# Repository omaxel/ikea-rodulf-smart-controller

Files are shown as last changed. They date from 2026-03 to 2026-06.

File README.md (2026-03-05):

# IKEA RODULF Sit/Stand Desk - WiFi Automation
Turn your manual IKEA RODULF desk into a smart, WiFi-controlled desk using an ESP8266 (NodeMCU) and a 2-channel relay module. Control it from any browser on your local network.

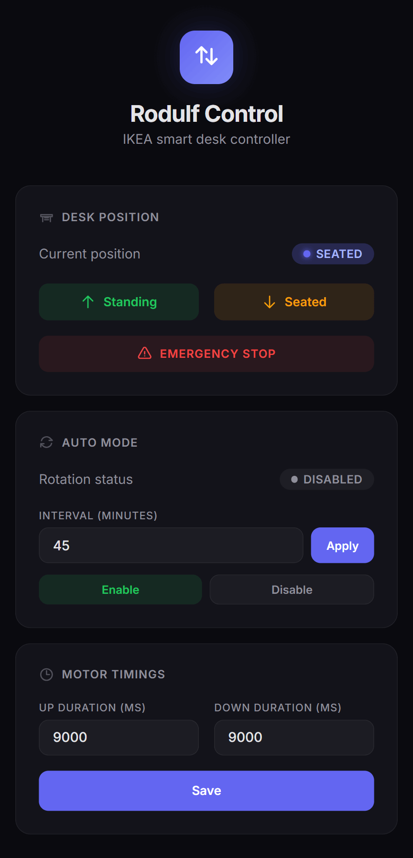
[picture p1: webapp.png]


## Table of Contents

- [Features](#features)
- [Hardware Requirements](#hardware-requirements)
- [Wiring & Connections](#wiring--connections)
- [Getting Started](#getting-started)
- [Repository Structure](#repository-structure)
- [Web Interface](#web-interface)
- [API Reference](#api-reference)
- [Limitations](#limitations)
- [Possible Improvements](#possible-improvements)

## Features

- **Remote control**: raise or lower the desk from any device on your WiFi network.
- **Original desk buttons still work**: relays are wired *in parallel* with the built-in buttons, so physical control is never disabled.
- **Auto-rotate mode**: automatically alternates between sitting and standing at a configurable interval (e.g. every 30 min).
- **Configurable motor timings**: set independent durations (ms) for up and down movements.
- **Persistent configuration**: all settings are saved to flash (LittleFS) and survive reboots.
- **Emergency stop**: instantly cuts power to both relays from the web UI.
- **Minimal footprint**: the entire UI is a single minified HTML page served from the ESP8266. No external server or cloud.

## Hardware Requirements

| Component | Qty | Notes |
|---|---|---|
| ESP8266 NodeMCU v1.0 (or compatible) | 1 | Wemos D1 Mini also works |
| 2-Channel 5 V Relay Module | 1 | Active-LOW, opto-isolated recommended |
| 5 V USB power supply | 1 | Powers the NodeMCU via micro-USB |
| IKEA RODULF sit/stand desk | 1 | Manual model with built-in up/down buttons |

## Wiring & Connections

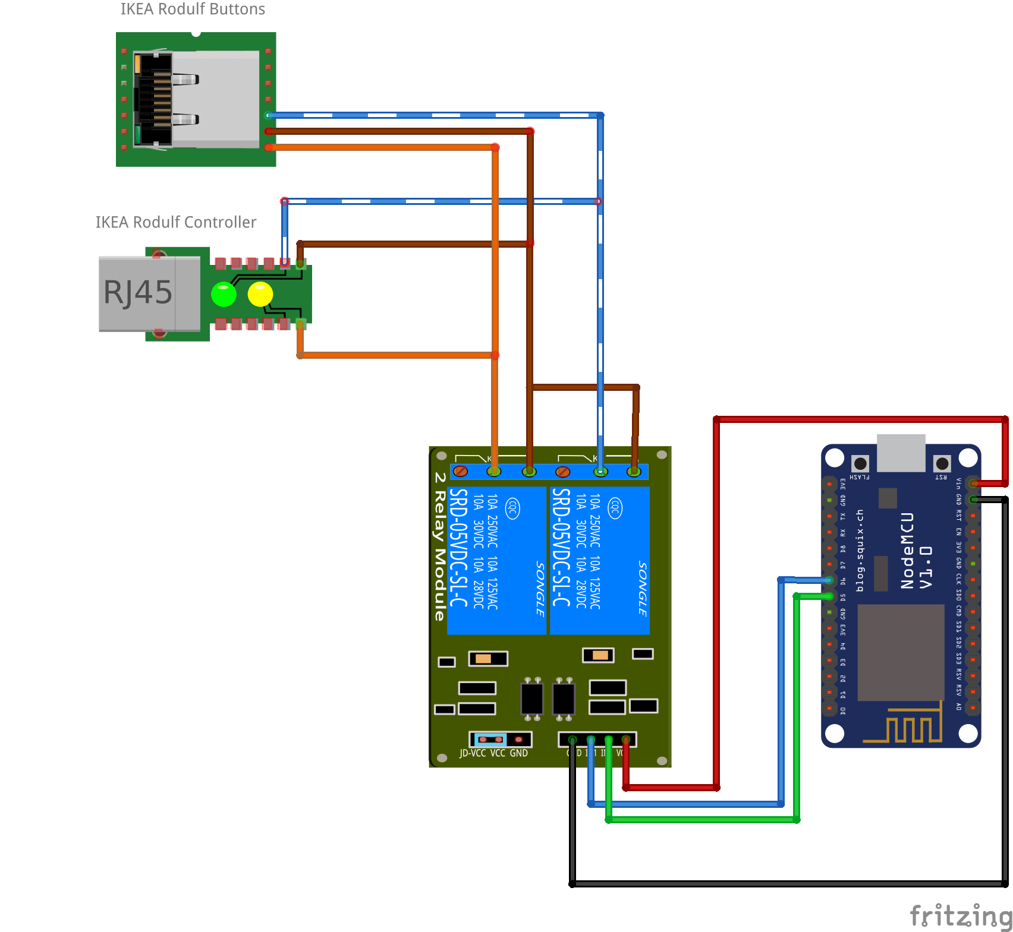
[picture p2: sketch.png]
Wiring diagram


### Relay Module to NodeMCU

| Relay Pin | NodeMCU Pin | Purpose |
|---|---|---|
| VCC | VIN (5 V) | Powers the relay coils |
| GND | GND | Common ground |
| IN1 | D5 | Relay 1 (UP) |
| IN2 | D6 | Relay 2 (DOWN) |

### Relay Module to Desk Buttons (RJ-45 Cable)

The RODULF desk buttons connect to an internal controller board via an **RJ-45 cable**. Only three of the eight wires are relevant:

| RJ-45 Wire Color | Function |
|---|---|
| **Orange** | DOWN signal |
| **Blue/white** | UP signal |
| **Brown** | Common (GND) |

The buttons work by shorting the signal wire to brown (GND). The relays are wired in parallel with these signals:

- **Relay 1 (UP)**: `COM` to brown wire, `NO` to blue/white wire.
- **Relay 2 (DOWN)**: `COM` to brown wire, `NO` to orange wire.

The RJ-45 output from the relay assembly must still be connected to the RODULF controller board so the desk receives the signals. Because the wiring is in parallel, the original physical buttons continue to work normally.

> **Important:** Use the `NO` (Normally Open) terminal on each relay, not `NC`. This keeps the motor off by default.

### Power

- NodeMCU is powered via micro-USB from a 5 V adapter.
- The relay module draws 5 V from the NodeMCU's VIN pin.
- The desk motor uses its own internal power supply; you are only switching button signals, not motor power.

## Getting Started

### 1. Install Arduino IDE & Board Support

1. Install the [Arduino IDE](https://www.arduino.cc/en/software) (v1.8+ or v2.x).
2. In **File > Preferences**, add this URL to **Additional Board Manager URLs**:
   ```
   http://arduino.esp8266.com/stable/package_esp8266com_index.json
   ```
3. In **Tools > Board > Board Manager**, search for `esp8266` and install the package.

### 2. Configure the Sketch

1. Open `ikea_rodulf_automation/ikea_rodulf_automation.ino`.
2. Set your WiFi credentials:
   ```cpp
   const char* ssid = "YourWiFiName";
   const char* password = "YourWiFiPassword";
   ```
3. (Optional) Adjust defaults:
   ```cpp
   // {timeUpMs, timeDownMs, isStanding, autoModeActive, autoIntervalMs}
   DeskConfig myConfig = {9000, 9000, false, false, 1800000};
   ```

### 3. Upload

1. Connect the NodeMCU via USB.
2. Select **Board:** `NodeMCU 1.0 (ESP-12E Module)` and the correct **Port**.
3. Set **Flash Size** to a partition with LittleFS (e.g. `4MB (FS:2MB OTA:~1019KB)`).
4. Click **Upload**.

### 4. Find the IP Address

Open **Serial Monitor** at 115200 baud after upload, or check your router's DHCP client list.

### 5. Open the Control Panel

Navigate to `http://<ESP_IP>/` from any browser on the same network.

### 6. (Optional) Developing the Frontend

```bash
cd frontend
npm install
npm run build     # produces index.min.html
```

Copy the minified output into the `handleRoot()` raw string in the `.ino` file.

## Repository Structure

```
├── README.md
├── sketch.png                         # Wiring diagram image
├── sketch.fzz                         # Fritzing source (editable)
├── fritzing_parts/                    # Custom Fritzing components
│   ├── 2-Channel 5v Relay Shield-fixed.fzpz
│   └── NodeMCUV1.0.fzpz
├── ikea_rodulf_automation/
│   └── ikea_rodulf_automation.ino     # Arduino sketch (ESP8266)
└── frontend/
    ├── index.html                     # Readable web UI source
    ├── index.min.html                 # Minified build (embedded in .ino)
    ├── package.json                   # npm build script
    └── package-lock.json
```

## Web Interface

Single HTML page with embedded CSS/JS. No frameworks or external dependencies at runtime.

- **Desk Position**: current state badge (Standing/Seated/Offline), buttons for up, down, and emergency stop.
- **Auto Mode**: enable/disable toggle and interval setting (minutes).
- **Motor Timings**: configure up/down relay duration (ms) and save to flash.
- **Auto-refresh**: polls `/status` every 3 seconds.

## API Reference

All endpoints use `GET` for simplicity.

| Endpoint | Parameters | Description |
|---|---|---|
| `/` | | Control panel (HTML) |
| `/status` | | JSON with current state |
| `/standing` | | Move desk up |
| `/seated` | | Move desk down |
| `/stop` | | Emergency stop |
| `/auto` | `enable=1\|0`, `interval=<min>` | Configure auto-rotate |
| `/config/set` | `up=<ms>`, `down=<ms>` | Set motor durations |

**Example `/status` response:**

```json
{
  "heightState": "standing",
  "autoMode": true,
  "intervalMinutes": 30,
  "timeUpMs": 9000,
  "timeDownMs": 9000,
  "isMoving": false
}
```

## Limitations

- **No position sensor**: the system tracks direction only, not actual height. Using the physical buttons will desync the reported state.
- **Timing calibration required**: you must measure your desk's actual travel time and enter it manually.
- **DHCP only**: the IP may change if your router reassigns it.
- **No authentication or HTTPS**: anyone on the same network can control the desk.

## Possible Improvements

- **mDNS**: reach the desk at `http://rodulf.local/` via `ESP8266mDNS`.
- **OTA updates**: flash new firmware over WiFi with `ArduinoOTA`.
- **Height sensor**: add HC-SR04 or VL53L0X for real position feedback.
- **Authentication**: basic HTTP auth or API key.
- **MQTT / Home Assistant**: publish state and accept commands over MQTT.
- **Button state detection**: read physical button signals on ESP8266 inputs to keep state in sync.
- **WebSocket updates**: replace polling with push for instant UI refresh.

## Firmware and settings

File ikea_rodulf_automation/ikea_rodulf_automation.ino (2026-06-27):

#include <ESP8266WiFi.h>
#include <ESP8266WebServer.h>
#include <LittleFS.h>

const char* ssid = "<SSID_HERE>";
const char* password = "<PASSWORD_HERE>";

const int relayUp = D5;    
const int relayDown = D6;

struct DeskConfig {
  unsigned long timeUpMs;      
  unsigned long timeDownMs;    
  bool isStanding;             
  bool autoModeActive;         
  unsigned long autoIntervalMs; 
};

DeskConfig myConfig = {9000, 9000, false, false, 1800000}; 
const char* CONFIG_PATH = "/desk_config.bin";

ESP8266WebServer server(80);
unsigned long movementStartTime = 0;   
unsigned long currentTargetDuration = 0; 
unsigned long lastAutoToggleTime = 0;   
bool isMoving = false;                 

// --- Persistence ---
void saveConfig() {
  File file = LittleFS.open(CONFIG_PATH, "w");
  if (file) {
    file.write((uint8_t*)&myConfig, sizeof(DeskConfig));
    file.close();
  }
}

void loadConfig() {
  if (LittleFS.exists(CONFIG_PATH)) {
    File file = LittleFS.open(CONFIG_PATH, "r");
    if (file) {
      file.read((uint8_t*)&myConfig, sizeof(DeskConfig));
      file.close();
    }
  }
}

// --- Motors ---
void stopMotors() {
  digitalWrite(relayUp, HIGH);
  digitalWrite(relayDown, HIGH);
  isMoving = false;
  movementStartTime = 0;
}

void startMovement(int pin, unsigned long duration, bool toStanding) {
  if (isMoving) return; 
  currentTargetDuration = duration;
  movementStartTime = millis();
  isMoving = true;
  myConfig.isStanding = toStanding;
  saveConfig(); 
  digitalWrite(pin, LOW); 
}

// --- Web Page HTML ---
void handleRoot() {
  String html = F(R"=====(
<!doctype html><html lang=en><meta charset=UTF-8><meta name=viewport content="width=device-width,initial-scale=1,viewport-fit=cover"><title>IKEA Rodulf Control Panel</title><link rel=preconnect href=https://fonts.googleapis.com><link href="https://fonts.googleapis.com/css2?family=Inter:wght@300;400;500;600;700&display=swap" rel=stylesheet><style>*,:before,:after{box-sizing:border-box;margin:0;padding:0}:root{--bg:#0a0a0f;--surface:#13131a;--surface-hover:#1a1a24;--border:#ffffff0f;--border-hover:#ffffff1f;--text:#e4e4e7;--text-dim:#8f8f9b;--accent:#6366f1;--accent-glow:#6366f140;--green:#22c55e;--green-dim:#22c55e1f;--amber:#f59e0b;--amber-dim:#f59e0b1f;--red:#ef4444;--red-dim:#ef44441a;--radius:16px;--radius-sm:10px}body{background:var(--bg);color:var(--text);min-height:-webkit-fill-available;padding:2rem 1rem;padding-top:max(2rem, env(safe-area-inset-top,0px));padding-bottom:max(2rem, env(safe-area-inset-bottom,0px));padding-left:max(1rem, env(safe-area-inset-left,0px));padding-right:max(1rem, env(safe-area-inset-right,0px));-webkit-font-smoothing:antialiased;font-family:Inter,-apple-system,BlinkMacSystemFont,sans-serif}.wrapper{max-width:720px;margin:0 auto}header{text-align:center;margin-bottom:2.5rem}header .logo{background:linear-gradient(135deg, var(--accent), #818cf8);width:56px;height:56px;box-shadow:0 0 32px var(--accent-glow);border-radius:16px;justify-content:center;align-items:center;margin-bottom:1rem;display:inline-flex}header .logo svg{color:#fff;width:28px;height:28px}header h1{letter-spacing:-.025em;margin-bottom:.25rem;font-size:1.5rem;font-weight:700}header p{color:var(--text-dim);font-size:.875rem;font-weight:400}.card{background:var(--surface);border:1px solid var(--border);border-radius:var(--radius);padding:1.5rem;transition:border-color .2s}.card:hover{border-color:var(--border-hover)}.card+.card{margin-top:1rem}.card-title{text-transform:uppercase;letter-spacing:.06em;color:var(--text-dim);align-items:center;gap:.5rem;margin-bottom:1.25rem;font-size:.75rem;font-weight:600;display:flex}.card-title svg{opacity:.5;width:16px;height:16px}.grid-2{grid-template-columns:1fr 1fr;gap:1rem;display:grid}.badge{letter-spacing:.03em;border-radius:999px;align-items:center;gap:6px;padding:4px 12px;font-size:.75rem;font-weight:600;display:inline-flex}.badge .dot{border-radius:50%;width:7px;height:7px;display:inline-block}.badge--active{background:var(--green-dim);color:var(--green)}.badge--active .dot{background:var(--green);box-shadow:0 0 6px var(--green)}.badge--inactive{color:var(--text-dim);background:#71717a1f}.badge--inactive .dot{background:var(--text-dim)}.badge--accent{background:var(--accent-glow);color:#a5b4fc}.badge--accent .dot{background:var(--accent);box-shadow:0 0 6px var(--accent)}.status-row{justify-content:space-between;align-items:center;margin-bottom:1.25rem;display:flex}.status-row span:first-child{color:var(--text-dim);font-size:.875rem}.btn{border-radius:var(--radius-sm);cursor:pointer;border:none;outline:none;justify-content:center;align-items:center;gap:8px;width:100%;padding:.7rem 1.25rem;font-family:inherit;font-size:.8125rem;font-weight:600;transition:all .15s;display:inline-flex}.btn svg{flex-shrink:0;width:16px;height:16px}.btn--stand{background:var(--green-dim);color:var(--green)}.btn--stand:hover{background:#22c55e38}.btn--sit{background:var(--amber-dim);color:var(--amber)}.btn--sit:hover{background:#f59e0b38}.btn--stop{background:var(--red-dim);color:var(--red);text-transform:uppercase;letter-spacing:.06em;grid-column:1/-1;font-size:.75rem}.btn--stop:hover{background:#ef444433}.btn--accent{background:var(--accent);color:#fff}.btn--accent:hover{box-shadow:0 0 20px var(--accent-glow);background:#4f46e5}.btn--ghost{color:var(--text-dim);border:1px solid var(--border);background:#ffffff0a}.btn--ghost:hover{color:var(--text);border-color:var(--border-hover);background:#ffffff14}.btn--sm{padding:.5rem 1rem;font-size:.75rem}.btn-group{gap:.5rem;display:flex}.field{flex-direction:column;gap:.375rem;display:flex}.field label{text-transform:uppercase;letter-spacing:.05em;color:var(--text-dim);font-size:.6875rem;font-weight:500}.input{color:var(--text);border:1px solid var(--border);border-radius:var(--radius-sm);background:#ffffff0a;outline:none;width:100%;padding:.6rem .875rem;font-family:inherit;font-size:.875rem;font-weight:500;transition:border-color .2s,box-shadow .2s}.input:focus{border-color:var(--accent);box-shadow:0 0 0 3px var(--accent-glow)}.input::placeholder{color:var(--text-dim)}.input::-webkit-inner-spin-button,.input::-webkit-outer-spin-button{-webkit-appearance:none;margin:0}.input[type=number]{-moz-appearance:textfield}.inline-field{gap:.5rem;display:flex}.inline-field .input{flex:1}.inline-field .btn{white-space:nowrap;width:auto}.timing-grid{grid-template-columns:1fr 1fr auto;align-items:end;gap:1rem;display:grid}.toast{background:var(--surface);border:1px solid var(--border-hover);border-radius:var(--radius-sm);color:var(--text);opacity:0;pointer-events:none;z-index:100;padding:.6rem 1.25rem;font-size:.8125rem;font-weight:500;transition:all .3s cubic-bezier(.16,1,.3,1);position:fixed;bottom:1.5rem;left:50%;transform:translate(-50%)translateY(100%);box-shadow:0 8px 32px #0006}.toast.show{opacity:1;transform:translate(-50%)translateY(0)}.toast{bottom:max(1.5rem, env(safe-area-inset-bottom,0px))}@media (width<=600px){.timing-grid{grid-template-columns:1fr 1fr}.timing-grid .btn{grid-column:1/-1}}@keyframes pulse{0%,to{opacity:1}50%{opacity:.4}}.pulse{animation:1.5s ease-in-out infinite pulse}@supports not (min-height:100dvh){body{min-height:calc(var(--vh,1vh) * 100)}}</style><div class=wrapper><header><div class=logo><svg xmlns="http://www.w3.org/2000/svg" fill="none" viewBox="0 0 24 24" stroke-width="2" stroke="currentColor"><path stroke-linecap="round" stroke-linejoin="round" d="M3 7.5 7.5 3m0 0L12 7.5M7.5 3v13.5m13.5-3L16.5 18m0 0L12 13.5m4.5 4.5V4.5"/></svg></div><h1>Rodulf Control</h1><p>IKEA smart desk controller</header><div class=card><div class=card-title><svg xmlns="http://www.w3.org/2000/svg" fill="none" viewBox="0 0 24 24" stroke-width="2" stroke="currentColor" aria-hidden="true"><path stroke-linecap="round" stroke-linejoin="round" d="M3 9h18v3H3V9Zm3 3v8m12-8v8M9 14h6m-6 3h6"/></svg> Desk Position</div><div class=status-row><span>Current position</span> <span id=heightState class="badge badge--accent pulse"><span class=dot></span>CONNECTING</span></div><div class=grid-2><button onclick='cmd("/standing")' class="btn btn--stand"><svg xmlns="http://www.w3.org/2000/svg" fill="none" viewBox="0 0 24 24" stroke-width="2" stroke="currentColor"><path stroke-linecap="round" stroke-linejoin="round" d="M4.5 10.5 12 3m0 0 7.5 7.5M12 3v18"/></svg> Standing</button> <button onclick='cmd("/seated")' class="btn btn--sit"><svg xmlns="http://www.w3.org/2000/svg" fill="none" viewBox="0 0 24 24" stroke-width="2" stroke="currentColor"><path stroke-linecap="round" stroke-linejoin="round" d="M19.5 13.5 12 21m0 0-7.5-7.5M12 21V3"/></svg> Seated</button> <button onclick='cmd("/stop")' class="btn btn--stop"><svg xmlns="http://www.w3.org/2000/svg" fill="none" viewBox="0 0 24 24" stroke-width="2" stroke="currentColor"><path stroke-linecap="round" stroke-linejoin="round" d="M12 9v3.75m-9.303 3.376c-.866 1.5.217 3.374 1.948 3.374h14.71c1.73 0 2.813-1.874 1.948-3.374L13.949 3.378c-.866-1.5-3.032-1.5-3.898 0L2.697 16.126ZM12 15.75h.007v.008H12v-.008Z"/></svg> Emergency Stop</button></div></div><div class=card><div class=card-title><svg xmlns="http://www.w3.org/2000/svg" fill="none" viewBox="0 0 24 24" stroke-width="2" stroke="currentColor"><path stroke-linecap="round" stroke-linejoin="round" d="M16.023 9.348h4.992v-.001M2.985 19.644v-4.992m0 0h4.992m-4.993 0 3.181 3.183a8.25 8.25 0 0 0 13.803-3.7M4.031 9.865a8.25 8.25 0 0 1 13.803-3.7l3.181 3.182"/></svg> Auto Mode</div><div class=status-row><span>Rotation status</span> <span id=autoState class="badge badge--inactive"><span class=dot></span>...</span></div><div class=status-row><span>Next toggle in</span> <span id=countdown>--:--</span></div><div class=field><label for=autoMinutes>Interval (minutes)</label><div class=inline-field style=margin-bottom:.75rem><input type=number id=autoMinutes class=input> <button onclick=setAuto() class="btn btn--accent btn--sm" style=width:auto>Apply</button></div></div><div class=btn-group><button onclick=toggleAuto(1) class="btn btn--stand btn--sm">Enable</button> <button onclick=toggleAuto(0) class="btn btn--ghost btn--sm">Disable</button></div></div><div class=card><div class=card-title><svg xmlns="http://www.w3.org/2000/svg" fill="none" viewBox="0 0 24 24" stroke-width="2" stroke="currentColor"><path stroke-linecap="round" stroke-linejoin="round" d="M12 6v6h4.5m4.5 0a9 9 0 1 1-18 0 9 9 0 0 1 18 0Z"/></svg> Motor Timings</div><div class=timing-grid><div class=field><label for=timeUp>Up duration (ms)</label> <input type=number id=timeUp class=input placeholder="e.g. 7500"></div><div class=field><label for=timeDown>Down duration (ms)</label> <input type=number id=timeDown class=input placeholder="e.g. 7500"></div><button onclick=saveTime() class="btn btn--accent" style=height:42px>Save</button></div></div></div><div id=toast class=toast></div><script>function showToast(t){const e=document.getElementById("toast");e.textContent=t,e.classList.add("show"),setTimeout(()=>e.classList.remove("show"),2200)}function updateStatus(){fetch("/status").then(t=>t.json()).then(t=>{const e=document.getElementById("heightState"),n=t.heightState.toUpperCase();e.innerHTML=`<span class="dot"></span>${n}`,e.className="STANDING"===n?"badge badge--active":"SEATED"===n?"badge badge--accent":"badge badge--inactive";const a=document.getElementById("autoState");a.innerHTML=t.autoMode?'<span class="dot"></span>ENABLED':'<span class="dot"></span>DISABLED',a.className=t.autoMode?"badge badge--active":"badge badge--inactive",document.getElementById("timeUp").value||(document.getElementById("timeUp").value=t.timeUpMs,document.getElementById("timeDown").value=t.timeDownMs,document.getElementById("autoMinutes").value=t.intervalMinutes);const o=document.getElementById("countdown");if(t.autoMode){const e=Math.floor(t.remainingMs/1e3),n=Math.floor(e/60),a=e%60;o.textContent=`${n}:${a.toString().padStart(2,"0")}`}else o.textContent="--:--"}).catch(()=>{document.getElementById("heightState").innerHTML='<span class="dot"></span>OFFLINE',document.getElementById("heightState").className="badge badge--inactive"})}function cmd(t){fetch(t).then(()=>{showToast(t.includes("standing")?"Moving up…":t.includes("seated")?"Moving down…":"Stopped!"),setTimeout(updateStatus,500)})}function toggleAuto(t){fetch(`/auto?enable=${t}`).then(()=>{showToast(t?"Auto mode enabled":"Auto mode disabled"),updateStatus()})}function setAuto(){const t=document.getElementById("autoMinutes").value;fetch(`/auto?interval=${t}`).then(()=>{showToast(`Interval set to ${t} min`),updateStatus()})}function saveTime(){const t=document.getElementById("timeUp").value,e=document.getElementById("timeDown").value;fetch(`/config/set?up=${t}&down=${e}`).then(()=>{showToast("Timings saved"),updateStatus()})}function setVh(){const t=window.visualViewport?window.visualViewport.height:window.innerHeight;document.documentElement.style.setProperty("--vh",.01*t+"px")}setVh(),window.addEventListener("resize",setVh),window.visualViewport&&window.visualViewport.addEventListener("resize",setVh),setInterval(updateStatus,3e3),updateStatus()</script>

)=====");
  server.send(200, "text/html", html);
}

// --- API Endpoints ---
void handleStatus() {
  unsigned long remainingMs = 0;

  if (myConfig.autoModeActive) {
    unsigned long elapsed = millis() - lastAutoToggleTime;

    if (elapsed < myConfig.autoIntervalMs) {
      remainingMs = myConfig.autoIntervalMs - elapsed;
    }
  }

  String json = "{";
  json += "\"heightState\":\"" + String(myConfig.isStanding ? "standing" : "seated") + "\",";
  json += "\"autoMode\":" + String(myConfig.autoModeActive ? "true" : "false") + ",";
  json += "\"intervalMinutes\":" + String(myConfig.autoIntervalMs / 1000 / 60) + ",";
  json += "\"timeUpMs\":" + String(myConfig.timeUpMs) + ",";
  json += "\"timeDownMs\":" + String(myConfig.timeDownMs) + ",";
  json += "\"isMoving\":" + String(isMoving ? "true" : "false") + ",";
  json += "\"remainingMs\":" + String(remainingMs);
  json += "}";

  server.send(200, "application/json", json);
}

void handleAuto() {
  if (server.hasArg("enable")) {
    myConfig.autoModeActive = (server.arg("enable") == "1");
    lastAutoToggleTime = millis(); 
    saveConfig();
  }
  if (server.hasArg("interval")) {
    myConfig.autoIntervalMs = (unsigned long)server.arg("interval").toInt() * 60000UL;
    saveConfig();
  }
  server.send(200, "text/plain", "OK");
}

void handleSetConfig() {
  if (server.hasArg("up")) myConfig.timeUpMs = (unsigned long)server.arg("up").toInt();
  if (server.hasArg("down")) myConfig.timeDownMs = (unsigned long)server.arg("down").toInt();
  saveConfig();
  server.send(200, "text/plain", "OK");
}

void setup() {
  Serial.begin(115200);
  digitalWrite(relayUp, HIGH);
  digitalWrite(relayDown, HIGH);
  pinMode(relayUp, OUTPUT);
  pinMode(relayDown, OUTPUT);

  LittleFS.begin();
  loadConfig();

  WiFi.begin(ssid, password);
  while (WiFi.status() != WL_CONNECTED) {
    Serial.println("Connecting to WiFi...");
    delay(500);
  }

  Serial.println("Connected to WiFi");

  server.on("/", HTTP_GET, handleRoot);
  server.on("/status", HTTP_GET, handleStatus);
  server.on("/auto", HTTP_GET, handleAuto); 
  server.on("/standing", HTTP_GET, [](){ startMovement(relayUp, myConfig.timeUpMs, true); server.send(200); });
  server.on("/seated", HTTP_GET, [](){ startMovement(relayDown, myConfig.timeDownMs, false); server.send(200); });
  server.on("/config/set", HTTP_GET, handleSetConfig);
  server.on("/stop", HTTP_GET, [](){ stopMotors(); server.send(200); });

  server.begin();
  lastAutoToggleTime = millis();

  Serial.println("HTTP Server started");
}

void loop() {
  server.handleClient();
  if (isMoving && (millis() - movementStartTime >= currentTargetDuration)) stopMotors();
  if (myConfig.autoModeActive && !isMoving && (millis() - lastAutoToggleTime >= myConfig.autoIntervalMs)) {
    if (myConfig.isStanding) startMovement(relayDown, myConfig.timeDownMs, false);
    else startMovement(relayUp, myConfig.timeUpMs, true);
    lastAutoToggleTime = millis(); 
  }
}
